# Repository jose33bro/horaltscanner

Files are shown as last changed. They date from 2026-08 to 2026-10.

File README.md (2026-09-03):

# HoralScanner

**Modular 3D Scanner & Reconstruction System**  
Raspberry Pi 4 + Creality V4.2.2 with custom USB firmware






---

## 🎯 What is HoralScanner?

HoralScanner is a complete **3D scanning and reconstruction system** built from the ground up for **Raspberry Pi 4**. It uses:

✅ **Custom STM32 USB firmware** — Direct motor/stepper control via USB CDC protocol  
✅ **Flask REST API** — Lightweight web service on port 5000  
✅ **Multi-sensor fusion** — Lidar (TF-Luna) + dual lasers + cameras (USB + CSI)  
✅ **3D reconstruction** — Open3D-powered point cloud processing  
✅ **Web dashboard** — Real-time control & monitoring  
✅ **Systemd auto-start** — Service runs on boot  

Perfect for:
- 🔬 Academic 3D scanning research
- 🖨️ Retrofitting old 3D printers
- 🎓 Educational robotics projects
- 🏭 Industrial inspection systems

---

## 🚀 Quick Start (Choose Your Path)

### Path A: Fresh Raspberry Pi OS (Recommended)
```bash
# 1. Flash latest Raspberry Pi OS to SD card
# Download: https://www.raspberrypi.com/software/

# 2. SSH into your Pi
ssh pi@raspberrypi.local

# 3. One-line installation
sudo bash -c "curl -sSL https://raw.githubusercontent.com/jose33bro/horaltscanner/main/setup_pi.sh | bash"

# 4. Reboot
sudo reboot

# 5. Access dashboard
# Open browser: http://<your-pi-ip>:5000
```
**Time:** 30-45 minutes | **Difficulty:** ⭐ Easy

---

### Path B: Manual Setup
See [QUICK_START.md](QUICK_START.md) for step-by-step instructions.

---

## 📊 Web Dashboard

Access at: `http://<your-pi-ip>:5000`

**Features:**
- 🔴 **Lasers:** Toggle left/right laser
- 🟡 **LED RGB:** Color picker + presets
- ⚙️ **Motors:** Move X/Y/Z by mm, homing, stop
- 💨 **Fans:** Control Pi/Creality/temperature fans (0-100%)
- 🌡️ **Temperature:** Real-time board sensor reading
- 📡 **Status:** GPIO & STM32 driver health

---

## 🔌 Hardware Setup

**Required:**
- Raspberry Pi 4 (4GB+)
- Creality V4.2.2 board (STM32F103RET6)
- USB cable (Micro-B, data-capable)
- Power supply

**GPIO Mapping (Raspberry Pi):**
```
GPIO27  → Laser Left (PWM-capable MOSFET, binary API)
GPIO22  → Laser Right (PWM-capable MOSFET, binary API)
GPIO18  → LED Red (PWM)
GPIO13  → LED Green (PWM)
GPIO19  → LED Blue (PWM)
GPIO23  → Pi Fan (PWM)
```

**STM32F103 Mapping (Creality V4.2.2):**
```
PC2/PB9/PC3  → Stepper X (step/dir/enable)
PB8/PB7/PC3  → Stepper Y (step/dir/enable)
PB6/PB5/PC3  → Stepper Z (step/dir/enable)
PA0          → Creality Fan (PWM)
PA8          → Temperature Fan (PWM)
PC5          → Board Temp Sensor
```

See `hardware/wiring_diagram.md` for complete pinout.

---

## 📡 REST API

All endpoints return JSON. Base URL: `http://<your-pi-ip>:5000`

### Lasers
```bash
POST /api/laser/left       {"state": true}      # Turn ON
POST /api/laser/right      {"state": false}     # Turn OFF
GET  /api/laser/status                          # Get both status
```

### LED
```bash
POST /api/led/color        {"r": 255, "g": 0, "b": 0}  # Set to red
GET  /api/led/status                            # Get current color
```

### Motors
```bash
POST /api/move/x           {"mm": 10.0}         # Move X by 10mm
POST /api/home/x                                # Home X axis
POST /api/home/all                              # Home all axes
POST /api/motor/stop       {"axis": "z"}        # Stop Z motor
GET  /api/motor/status                          # Get positions
```

### Fans
```bash
POST /api/fan/pi           {"percent": 50}      # Set Pi fan to 50%
POST /api/fan/creality     {"speed": 0.75}      # Set Creality fan
POST /api/fan/temperature  {"pwm": 0.5}         # Set temp fan
GET  /api/fan/status                            # Get all speeds
```

### Temperature
```bash
GET  /api/temperature/board                     # Get °C
GET  /api/temperature/all                       # Get all sensors
```

### System
```bash
GET  /api/status                                # Health check
GET  /                                          # Web dashboard
```

**Full API Reference:** See [USAGE.md](USAGE.md)

---

## 📁 Project Structure

```
horaltscanner/
├── software/
│   ├── api/                    # Flask API server
│   │   ├── horalscanner_api.py # Main entry point (port 5000)
│   │   ├── motor_control.py    # X/Y/Z axis orchestration
│   │   ├── laser_control.py    # GPIO laser control
│   │   ├── led_control.py      # RGB LED control
│   │   ├── camera_driver.py    # USB & Pi Camera capture
│   │   ├── lidar_driver.py     # TF-Luna lidar driver
│   │   └── scanner_engine.py   # Multi-sensor scan orchestration
│   │
│   ├── web/                    # Web dashboard (HTML/CSS/JS)
│   │   ├── index.html
│   │   ├── app.js
│   │   └── style.css
│   │
│   ├── drivers/                # Hardware abstraction
│   │   ├── stm32_driver.py     # Creality USB interface
│   │   └── gpio_driver.py      # Raspberry Pi GPIO
│   │
│   ├── scripts/                # Utilities
│   │   └── update.sh           # Auto-update script
│   │
│   └── tests/                  # Test suite
│       └── test_*.py
│
├── firmware/
│   ├── creality_v422/
│   │   └── usb_firmware.c      # STM32F103 firmware (custom USB protocol)
│   │
│   └── raspberry_pi/
│       ├── usb_driver.py       # Python USB CDC driver
│       ├── motor_control.py    # Motor orchestration
│       ├── camera_acquisition.py
│       ├── lidar_acquisition.py
│       └── scanner_app.py      # Main scanning app
│
├── hardware/
│   ├── wiring_diagram.md       # GPIO & pin mappings
│   └── README.md
│
├── docs/
│   └── usb_protocol.md         # USB CDC protocol spec
│
├── setup_pi.sh                 # Complete Pi setup script
├── QUICK_START.md              # Installation guide (3 paths)
├── DEPLOYMENT.md               # Production deployment guide
├── USAGE.md                    # API reference & examples
├── CHANGELOG.md                # Version history
├── requirements.txt            # Python dependencies
└── VERSION                     # Version number
```

---

## 🛠️ Technology Stack

| Layer | Technology | Purpose |
|---|---|---|
| **Language** | Python 3.9+ (69%) | Backend, drivers, scanning logic |
| **Web Framework** | Flask 2.3+ | REST API server |
| **Hardware I/O** | RPi.GPIO, gpiozero | GPIO control |
| **USB/Serial** | pyserial | STM32 communication |
| **Vision** | OpenCV 4.5+ | Camera capture, image processing |
| **3D** | Open3D 0.12+ | Point cloud reconstruction |
| **Math** | NumPy, SciPy | Scientific computing |
| **Frontend** | Vanilla JS, HTML5, CSS3 | Web dashboard |
| **Init** | systemd | Service management |
| **OS** | Raspberry Pi OS (Bookworm) | Base system |

---

## 📋 Scripts Included

### `setup_pi.sh` — Full Setup
```bash
sudo bash setup_pi.sh --full          # Fresh system + code + service
sudo bash setup_pi.sh --install       # Skip system updates
sudo bash setup_pi.sh --update        # Update code only
sudo bash setup_pi.sh --quick-test    # Test imports
```

### `software/scripts/update.sh` — Auto-Update
```bash
bash /home/pi/horaltscanner/software/scripts/update.sh
```
- Backs up current state
- Pulls latest code
- Updates Python deps
- Restarts service

---

## ✅ Verification Checklist

After installation, verify:

- [ ] SSH access to Pi works
- [ ] Service running: `sudo systemctl status horalscanner`
- [ ] Web dashboard loads: `http://<pi-ip>:5000`
- [ ] GPIO driver connected (in dashboard Status card)
- [ ] STM32 driver connected (when board is powered)
- [ ] Can toggle laser via dashboard or API
- [ ] Can read board temperature
- [ ] Can move motors (after homing)

---

## 🐛 Troubleshooting

### Service won't start
```bash
# Check logs
sudo journalctl -u horalscanner -n 50

# If GPIO fails
sudo usermod -a -G gpio pi
sudo reboot
```

### Can't connect to Creality board
```bash
# List serial devices
ls /dev/tty*

# Check USB
lsusb
dmesg | grep -i stm32
```

### Port 5000 in use
```bash
sudo lsof -i :5000
sudo kill -9 <PID>
```

Full troubleshooting: See [DEPLOYMENT.md](DEPLOYMENT.md) or [QUICK_START.md](QUICK_START.md)

---

## 📚 Documentation

| Document | Purpose |
|---|---|
| [QUICK_START.md](QUICK_START.md) | 3 installation paths, setup verification |
| [DEPLOYMENT.md](DEPLOYMENT.md) | Production deployment, systemd, troubleshooting |
| [USAGE.md](USAGE.md) | Full API reference with cURL examples |
| [CHANGELOG.md](CHANGELOG.md) | Version history and release notes |
| `hardware/wiring_diagram.md` | Complete GPIO & pin mappings |
| `docs/usb_protocol.md` | USB CDC protocol specification |

---

## 🔐 Security Notes

⚠️ **This project is for local development/research:**

- Default user: `pi` / password: `raspberry` (change immediately!)
- API has no authentication (designed for LAN only)
- No HTTPS (use only on trusted networks)
- GPIO access available to `pi` user

For production deployment:
1. Change default password
2. Disable SSH password auth (use keys only)
3. Use firewall (ufw)
4. Add reverse proxy with authentication
5. Use VPN for remote access

---

## 📈 Performance

Typical performance on Raspberry Pi 4 (4GB):

| Task | Performance |
|---|---|
| API response time | <50ms |
| Motor command | 10-50ms |
| GPIO toggle | 1-5ms |
| Camera capture | 30-60fps (640x480) |
| Lidar scan | 5Hz (200pt/s) |
| 3D reconstruction | 1-5 min for 1000+ points |

---

## 📄 License

MIT License - See LICENSE file for details

---

## 🤝 Contributing

1. Fork the repository
2. Create a feature branch (`git checkout -b feature/amazing-feature`)
3. Commit changes (`git commit -m 'Add amazing feature'`)
4. Push to branch (`git push origin feature/amazing-feature`)
5. Open a Pull Request

---

## 📞 Support

- **Issues:** https://github.com/jose33bro/horaltscanner/issues
- **Discussions:** https://github.com/jose33bro/horaltscanner/discussions

---

## 🎉 Status

- ✅ **v1.0.0** — Stable release
  - Web dashboard
  - Flask API
  - GPIO/STM32 drivers
  - Systemd service
  - Full documentation

---

**Made with ❤️ for 3D scanning enthusiasts**

Get started now: [QUICK_START.md](QUICK_START.md)

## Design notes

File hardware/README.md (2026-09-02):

# Matériel cible

- Raspberry Pi 4 (4Go)
- Carte mère Creality V4.2.2 (STM32F103)
- Axe X: plateau tournant
- Axe Y: translation avec endstop (point 0 lidar TF-Luna)
- Axe Z: ajustement hauteur
- Lidar TF-Luna (USB)
- Caméra USB Logitech
- Caméra Pi V3 noire (CSI)
- 2 lasers pilotés via GPIO du Raspberry Pi

La logique moteur est embarquée côté firmware STM32, la synchronisation capteurs est orchestrée côté Raspberry Pi.

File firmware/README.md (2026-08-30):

# Firmware USB personnalisé (Creality V4.2.2)

Ce dossier contient une base de firmware USB custom pour STM32F103 (carte Creality V4.2.2).

## Responsabilités
- Communication USB bidirectionnelle avec le Raspberry Pi
- Commandes moteurs sur axes X/Y/Z
- Lecture endstop Y
- Point de synchronisation avec les capteurs côté Raspberry Pi

## Protocole texte minimal (USB CDC)
- `PING` → `OK PONG`
- `MOVE <AXIS> <STEPS> <SPEED>` → `OK MOVE`
- `HOME Y` → `OK HOME`
- `ENDSTOP Y` → `OK ENDSTOP <0|1>`
- `SYNC <TOKEN>` → `OK SYNC <TOKEN>`

Le code source de référence est dans `creality_v422/src/main.c`.

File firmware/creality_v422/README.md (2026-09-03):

# Firmware HoralScanner pour Creality V4.2.2

Ce firmware cible uniquement une carte Creality V4.2.2 équipée d'un
**STM32F103RET6**. Il implémente le protocole décrit dans
`docs/usb_protocol.md` sur le CH340 de la carte à 115200 bauds.

## Sécurité

- Les sorties chauffantes PA1 et PA2 sont forcées à l'arrêt.
- Les moteurs sont désactivés au démarrage, après chaque mouvement et après
  cinq secondes sans commande.
- Un déplacement vers la butée s'arrête dès que l'entrée correspondante devient
  active. Les contacts normalement fermés de X, Y et Z sont actifs à l'état
  haut lorsqu'ils s'ouvrent sur la butée.
- Une recherche d'origine est abandonnée après 120 secondes.
- Le repère Y arrête uniquement le référencement. Si PA6 est déjà actif au
  début de `HOME Y` (ou lorsque `HOME ALL` atteint Y), le plateau continue dans
  le sens de référencement jusqu'à la libération stable du repère, puis jusqu'à
  son prochain déclenchement stable. La libération et le déclenchement sont
  validés pendant 20 ms pour rejeter les rebonds. Les rotations `MOVE Y`
  franchissent toujours le repère afin que le plateau accomplisse un tour
  complet.
- Les mouvements utilisent une rampe d'accélération et de décélération pour
  éviter les résonances et pertes de pas du plateau.
- La vitesse de référencement est limitée séparément pour chaque mécanique:
  X et Z à 400 pas/s, Y à 100 pas/s après accélération progressive.
- Les trois axes partagent la sortie d'activation PC3.

Ne flashez pas ce binaire sur une carte GD32 ou une autre révision. Débranchez
les moteurs avant le premier test de communication. Vérifiez ensuite chaque
fin de course avec `ENDSTOP X`, `ENDSTOP Y` et `ENDSTOP Z` avant d'utiliser
`HOME`.

## Compilation

Depuis la racine du dépôt:

```bash
bash software/scripts/build_creality_firmware.sh
```

Le binaire est créé dans:

```text
firmware/creality_v422/build/firmware.bin
```

Le linker place l'application à `0x08007000`, après le bootloader Creality de
28 Kio. La table des vecteurs est déplacée au même endroit.

## Flash par carte microSD

1. Utilisez une carte microSD FAT32 de 8 Go ou moins.
2. Copiez uniquement le binaire à la racine, sous le nom `firmware.bin`.
3. Coupez complètement l'alimentation 24 V et débranchez l'USB.
4. Insérez la microSD, puis remettez l'alimentation 24 V.
5. Attendez 30 secondes sans couper l'alimentation.
6. Coupez l'alimentation, retirez la carte, puis reconnectez l'USB.

Le fichier est généralement renommé `FIRMWARE.CUR` après un flash réussi.
Après reconnexion au Raspberry Pi:

```bash
sudo systemctl stop horalscanner
sudo /home/pi/horaltscanner_env/bin/python3 -c \
  "import serial,time; s=serial.Serial('/dev/ttyUSB0',115200,timeout=2); time.sleep(2); s.write(b'PING\n'); s.flush(); print(repr(s.readline())); s.close()"
sudo systemctl restart horalscanner
```

La réponse attendue est `b'OK PONG\r\n'`.

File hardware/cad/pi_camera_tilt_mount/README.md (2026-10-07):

# Support orientable pour Pi Camera V3

Ce répertoire contient la base du support orientable de Pi Camera V3 et son
test d'encombrement. La plaque verticale et la tablette inférieure forment un
support en L; les deux oreilles supérieures reçoivent l'axe M3 de la caméra.

## Fichiers générés

- `stl/pi_camera_tilt_base.stl` : base orientable définitive;
- `stl/fit_test_rear_cavity_30.45x38.2.stl` : test d'encombrement à imprimer
  avant la base;
- `stl/adjustment_rod_M5x50_ball6.5_square_m3.stl` : tige d'ajustement M5
  sur 50 mm, bille Ø 6,5 mm côté caméra et carré côté roue/plateau, avec trou
  M3 central dans le carré;
- `stl/wheel_crank_50mm_square_m3.stl` : roue/crank de 50 mm de diamètre avec
  carré de montage et trou M3 central pour serrage sur plaque de 3 mm;
- `stl/camera_carrier_v3_25x24_tab4.8.stl` : berceau qui porte la carte Pi
  Camera Module 3 (noir/NoIR, 25 × 24 mm, 4 trous Ø2,5 mm en carré 21 mm) et
  se clipse entre les oreilles de la base sur l'axe M3 (tenon Ø 3,40 mm), avec
  un patin plat au dos où vient appuyer la bille de la tige d'ajustement;
- `stl/camera_front_cover_v3_clip.stl` : cache avant (côté objectif) qui
  tient la caméra sur le berceau sans vis — 4 pions se clipsent par
  pression dans les mêmes 4 trous Ø2,5 mm, en traversant la carte et le
  berceau, avec une ouverture centrale Ø11 mm pour l'objectif.

Les autres fichiers STL éventuellement présents dans ce répertoire ne sont pas
générés par `generate.py`.

## Cotes fonctionnelles de la base

- plaque verticale : 30,45 × 38,20 × 3,20 mm;
- tablette inférieure vers l'avant : projection 24,00 mm;
- parois latérales de tablette : 3,20 mm d'épaisseur et 6,20 mm de hauteur;
- rails sous la tablette : 5,00 mm de large, 16,00 mm de long et 5,00 mm de
  descente, avec un avant-trou horizontal Ø 2,70 mm dans chaque rail et une
  découpe de 3,00 mm depuis l'avant pour dégager le passage M3;
- passage de nappe du câble CSI dans la partie tablette : ouverture centrale
  vers l'avant, dans la tablette de 24,00 mm.
- oreilles : projection 8,70 mm, largeur 8,50 mm, hauteur 5,99 mm et espace
  central 5,33 mm;
- trou d'axe traversant : Ø 3,40 mm;
- trou de fixation M5 sur la plaque verticale, centré entre les oreilles et à 22,00 mm du haut;
- fenêtre CSI dans la plaque verticale : 18,00 × 9,56 mm, centrée en bas et décalée vers l'avant;
- encoches de dégagement dans les parois latérales de la tablette (côté
  intérieur) là où la carte caméra (25,00 mm de large) est plus large que
  l'écart utile entre parois (24,05 mm);
- poche de dégagement dans la face supérieure de la tablette, sous la zone
  balayée par le bord bas du berceau pendant le pivotement (voir plage de
  réglage ci-dessous) : sans elle, le berceau coince contre la tablette dès
  une fraction de degré dans un des deux sens de rotation.

## Plage de réglage de l'inclinaison

Le berceau pivote autour de l'axe M3 des oreilles; au repos (0°) il touche
la tablette, qui sert de butée naturelle d'un côté. La plage utile réelle,
vérifiée géométriquement (volumes de recouvrement nuls entre solides), est
**-15° à +9°** par rapport au repos :

- jusqu'à -15° : dégagement complet, aucun contact parasite;
- au-delà de +9° : le berceau commence à empiéter dans la fenêtre CSI de la
  plaque verticale (pas un contact matière, mais un risque de pincer la
  nappe du câble CSI qui passe par cette fenêtre).

Cette plage asymétrique convient à l'usage prévu : la caméra est déjà
orientée vers le bas (vers le plateau tournant) au repos, donc le sens
disponible le plus large (-15°, qui l'incline encore plus vers le bas) est
celui qui compte le plus.

## Cotes du berceau caméra (`camera_carrier_v3_25x24_tab4.8.stl`)

- plaque porte-caméra : 25,00 × ~29,00 × 2,00 mm (hauteur ajustée pour
  rejoindre le bas des oreilles), espacée de 9,00 mm derrière la face avant
  de la plaque principale (jeu pour la tige d'ajustement et pour que le
  bord bas du berceau dégage la plaque sur toute la plage de réglage);
- 4 trous de fixation M2/M2,5 Ø 2,50 mm en carré de 21,00 mm, cotes
  officielles du Camera Module 3 (25 × 24 mm, standard ou NoIR);
- tenon de charnière : largeur 4,80 mm (jeu dans l'espace de 5,33 mm entre
  les oreilles), même profil arrondi que les oreilles, trou d'axe Ø 3,40 mm
  aligné avec celui de la base; profondeur dimensionnée pour ne chevaucher
  que la propre plaque du berceau (fusion solide), sans jamais pénétrer
  dans la plaque principale;
- patin plat au dos (remplace l'ancienne fossette sphérique) : rayon
  6,00 mm, profondeur 0,60 mm, où vient appuyer la bille de la tige. Une
  sphère contre un plan garde un contact valide à n'importe quel angle,
  contrairement à une fossette sphérique de même rayon que la bille, dont
  la plage utile ne dépassait que ±2,4° avant perte de contact.

## Cotes du cache avant (`camera_front_cover_v3_clip.stl`)

- plaque : 25,00 × 24,00 × 1,60 mm, plaquée contre la face avant de la carte
  caméra (côté objectif);
- ouverture centrale Ø 11,00 mm, centrée sur le carré de trous de montage,
  pour dégager l'objectif;
- 4 pions de clipsage Ø 2,30 mm (léger serrage dans les trous Ø 2,50 mm de
  la carte), longueur de pénétration ~2,90 mm (épaisseur carte + berceau,
  sans atteindre la face arrière du berceau), pointe conique de 0,80 mm pour
  faciliter l'insertion. Remplace les vis/écrous M2,5 : pousser le cache en
  face, les pions traversent la carte et se bloquent par friction dans les
  trous du berceau.

## Génération

Le générateur paramétrique `generate.py` dépend des bindings OpenCascade
fournis par le paquet `cadquery-ocp`. Dans un environnement Python dédié :

```bash
python3 -m pip install cadquery-ocp
python3 hardware/cad/pi_camera_tilt_mount/generate.py
```

Exécuter la commande depuis la racine du dépôt. Elle vérifie les solides avant
l'export et remplace les six STL listés ci-dessus.

## Impression et montage

1. Imprimer d'abord le test d'encombrement à plat et vérifier l'espace arrière.
2. Imprimer la base avec le grand dos de la plaque contre le plateau.
3. Utiliser des supports « Everywhere », angle de surplomb 55°, densité 12 %,
   interface activée (2 couches) et distance Z de 0,22 mm.
4. Poser la carte Pi Camera Module 3 contre la face avant du berceau
   (`camera_carrier_v3_25x24_tab4.8.stl`), trous alignés.
5. Clipser le cache avant (`camera_front_cover_v3_clip.stl`) par-dessus : les
   4 pions traversent les trous de la carte et se bloquent par pression dans
   les trous du berceau — pas de vis ni d'écrou nécessaires.
6. Installer le berceau (carte + cache) entre les oreilles de la base avec
   l'axe M3 (pivot), sans le bloquer serré pour qu'il puisse encore pivoter.
7. Visser la tige d'ajustement (`adjustment_rod_M5x50_ball6.5_square_m3.stl`)
   dans le bossage taraudé M5 au dos de la plaque, bille côté caméra, jusqu'à
   ce qu'elle appuie contre le patin plat au dos du berceau.
8. Clipser la roue (`wheel_crank_50mm_square_m3.stl`) sur le carré de la tige
   avec une vis M3 et tourner pour régler finement l'inclinaison (plage
   utile -15°/+9°, voir « Plage de réglage de l'inclinaison » plus haut); le
   berceau pivote autour de l'axe des oreilles.
9. Fixer la base par les deux rails inférieurs avec des vis M3.

Le profil d'impression détaillé est documenté dans
[`../../../materiel/README_support_camera_pi_pivot_reglable.md`](../../../materiel/README_support_camera_pi_pivot_reglable.md).

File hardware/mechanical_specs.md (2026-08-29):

# HoralScanner — Mechanical Specifications

## Design Reference Frame

```
        Z-Axis (Height)
             ↑
             |
   Y-Axis ←--+--→ X-Axis (Rotation)
       (Forward/Back)
             
    Rear (Y=0) -------- Front (Y=100)
       ↑                    ↑
    Endstop         Object detection
```

---

## Ball Screw Specifications

### M5 × 40 Assembly (All Axes)

| Parameter | Value | Notes |
|---|---|---|
| **Thread Pitch** | M5 × 0.8 mm | ISO metric |
| **Ball Diameter** | Ø6.5 mm | Grade 25 hardened steel |
| **Ball Preload** | Light (1–2 N/mm²) | Reduces backlash to <0.1 mm |
| **Lead** | 5 mm/rev | 1 revolution = 5 mm travel |
| **Maximum Speed** | 20,000 steps/sec | Stepper limit (from motor_control.py) |
| **Max Linear Speed** | ~100 mm/sec | Calculated: 20k steps/sec ÷ 3200 steps/mm × 16 microsteps |
| **Preload Spring** | Light spring or adjustable collar | Rear bearing (fixed); front bearing (floating) |
| **Lubrication** | NLGI-2 lithium grease | Reapply every 500 hours of operation |

### Calculation: Steps per mm
```
Steps/mm = (200 steps/rev × 16 microsteps) / 5 mm pitch
         = 3200 / 5
         = 640 steps/mm
```

### Motion Limits

| Axis | Travel Range | Position Min | Position Max | Purpose |
|---|---|---|---|---|
| **X (Rotation)** | 0–360° | 0 mm | 360 mm | Continuous rotation platform |
| **Y (Forward/Back)** | 0–100 mm | 0 mm (rear, endstop) | 100 mm (front) | Linear scan axis |
| **Z (Height)** | 0–50 mm | 0 mm (+5 mm offset) | 50 mm | Camera height adjustment |

---

## 3D-Printed Parts (PLA)

### Camera Support Plate

**Overall Dimensions:**
```
   Front
      ↑
    7 mm (width)
      ↑
   ┌──────────────┐
   │  Socket      │ 1 mm (height/thickness)
   │   Ø6.9 mm    │ ← centered
   │  (centered)  │
   │    │││       │ ← 4 petal retainers (depth)
   └──┴─┴─┴──────┘
   28.05 mm (length)
```

**Key Specifications:**

| Feature | Dimension | Tolerance | Notes |
|---|---|---|---|
| **Length** | 28.05 mm | ±0.1 mm | Attachment footprint |
| **Width** | 7 mm | ±0.2 mm | Camera connector clearance |
| **Thickness** | 1 mm | ±0.2 mm | Minimal weight |
| **Socket Diameter** | Ø6.9 mm | ±0.05 mm | Logitech USB camera lens fit |
| **Socket Depth** | 4 mm | ±0.1 mm | Retainer petal depth |
| **Petal Retainers** | 4× radial petals | — | Grip camera housing without glue |
| **M3 Clearance Holes** | Ø3.2 mm | ±0.1 mm | Screw pass-through (not tapped) |
| **Hole Spacing** | 2× on 14 mm centers | ±0.2 mm | Frame attachment points |
| **Socket Centering** | Center ±0.1 mm | — | Optical axis alignment |

**Material Properties:**
- **Infill:** 15% grid pattern (sufficient for non-load-bearing bracket)
- **Layer Height:** 0.15 mm (for surface finish)
- **Support Material:** Breakaway supports on underside; clean before installation
- **Print Speed:** 60–80 mm/s (avoid warping at thin cross-section)
- **Bed Temp:** 60°C; Nozzle: 210°C

**Load Limits:**
- **Supported Mass:** <200 g (USB camera + lens)
- **Retention Force:** ~5 N (petal friction)
- **Failure Mode:** Petal cracking under excessive insertion torque

---

### Base Plate

**Overall Dimensions:**
```
    M5 Hole
      ↓ (Rear side)
    ┌────────────────────────┐
    │                        │
    │      BASE PLATE        │  Vertical offset: +5 mm
    │      (PLA)             │  from origin (Y=0, Z=0 ref)
    │                        │
    └─────────────────────────┘
      Rear (Y=0) ←→ Front (Y=100)
```

**Key Specifications:**

| Feature | Specification | Tolerance | Notes |
|---|---|---|---|
| **Length** | 100 mm | ±1 mm | Full Y-axis travel |
| **Width** | 50 mm | ±1 mm | Z-axis carriage mount |
| **Thickness** | 3 mm | ±0.2 mm | Structural rigidity |
| **M5 Tapped Hole** | M5 × 0.8 ISO | ±0.1 mm | Ball screw mounting (Z-axis) |
| **Hole Position** | Center rear, 10 mm from edge | ±0.5 mm | — |
| **Hole Type** | Tapped (M5×0.8) or threaded insert | — | Must support axial load of ball screw |
| **Vertical Offset Reference** | +5 mm above absolute origin | ±0.5 mm | **Calibration height** for TF-Luna Y-sync |
| **Orientation Marking** | "Rear → Front" engraved or labeled | — | Assembly guide |
| **Surface Finish** | Smooth (post-processed if needed) | — | Reduce friction on Y-carriage |

**Material Properties:**
- **Infill:** 25% (load-bearing structural part)
- **Layer Height:** 0.2 mm (strength > finish)
- **Support Material:** None (print with flat base down)
- **Print Speed:** 50–60 mm/s (ensure dimensional accuracy)
- **Bed Temp:** 60°C; Nozzle: 210°C

**Load Limits:**
- **Supported Mass:** <500 g (full scanner head + camera + laser)
- **M5 Thread Tensile Strength:** ~2 kN (PLA nominal)
- **Deflection:** <0.5 mm under full load (measure with dial indicator)

**Mounting to Frame:**
- Secure to Z-carriage with M3 fasteners (2× clearance holes if present)
- Use M3 nylon washers under screw heads to reduce PLA stress concentration
- Apply loctite (medium strength) to M5 ball screw socket

---

## Critical Dimensions & Calibration

### Camera Support Plate → Z-Carriage Interface

**Assembly Sequence:**

1. **Mount plate on Z-carriage:**
   - Position: Centered on carriage, front face (toward object)
   - Height: Flush with carriage top surface
   - Fasteners: M3×10 pan-head screws, 1.5–2 N·m torque

2. **Insert camera into socket:**
   - Logitech USB camera lens first (Ø6.9 mm)
   - Push gently until 4 petals engage connector housing
   - Verify horizontal (spirit level)
   - Do NOT force (risk breaking petals)

3. **Cable routing:**
   - USB cable exits toward rear
   - 100 mm slack for Y-motion
   - Cable tie at rear frame

**Clearance Check:**
- **Plate to ball screw:** 1 mm minimum (avoid binding during Z travel)
- **Socket to camera:** 0 mm (tight fit is intentional; creates retention)
- **Camera lens to object:** 50–200 mm working distance

---

### Base Plate → Frame Interface

**M5 Tapped Hole (Ball Screw Mounting):**

1. **Prepare hole:**
   - Clean PLA threads of any residual plastic
   - Test-thread M5 machine screw (should turn smoothly, no crunching)
   - If threads damaged, drill out Ø5.5 mm and install **M5 threaded insert** (helicoil type)

2. **Install ball screw:**
   - Thread M5×40 ball screw into tapped hole
   - Screw in until **slight resistance** (ball nut engagement)
   - Rotate screw manually: should turn **freely with light resistance**
   - If stuck: back out and apply light grease to threads

3. **Secure with lock nut:**
   - Thread M5 lock nut onto exposed ball screw
   - Torque: 10–15 N·m (prevents axial motion but allows rotation)
   - Verify screw doesn't rotate when nut is tightened

**Vertical Offset Calibration (+5 mm):**
- Measure Z-position of base plate **relative to its lowest position**
- When Z-axis is fully retracted, base plate should be **5 mm above origin**
- This ensures TF-Luna (mounted on Y-carriage) can measure object at optimal distance (50–100 mm)
- **Do NOT change this offset** without recalibrating `lidar_driver.py` offset constant

---

## Endstop Configuration

### Y-Axis Endstop (Rear Limit, Y=0)

**Mechanical:**
- **Type:** Microswitch, normally-open (NO), lever-activated
- **Mounting:** Fixed to rear frame or carriage rail
- **Activation Point:** Y-carriage contacts lever exactly at Y=0
- **Travel Distance to Stop:** <2 mm (minimal over-travel)

**Electrical:**
- **Wiring:** Common pin → GND; NO pin → Creality endstop input
- **Pull-up:** Enabled in Creality firmware (internal 10k resistor)
- **Logic:** Active LOW (switch closes = GND signal)

**Calibration:**
1. Jog Y-axis toward rear manually using dashboard
2. When carriage contacts endstop, listen for **click** from microswitch
3. In `motor_control.py`, set `home_offset_y = 0`
4. Run `api/home/y` endpoint; verify position resets to 0.0

---

## Electrical Connector Specifications

### Stepper Motor Connectors

**Wiring (4-wire, bipolar NEMA 17):**
```
Pin 1: Coil A+  (Red)
Pin 2: Coil A-  (Green)
Pin 3: Coil B+  (Blue)
Pin 4: Coil B-  (Black)

Creality V4.2.2 Motor Header Layout:
┌──────────┐
│ 1  2  3  4 │  (Typical: GND, STEP, DIR, +V)
│ GND STP DIR +V│
└──────────┘
```

**Cable Specifications:**
- **Type:** 4-conductor shielded cable (UTP acceptable for short runs)
- **AWG:** 22–26 gauge (1 m runs acceptable)
- **Connector:** Dupont 2.54mm female headers or equivalent
- **Length:** <1 m (minimize noise coupling)

---

## Tolerance & Fit Summary

| Component | Critical Tolerance | Rationale |
|---|---|---|
| **Camera Socket (Ø6.9)** | ±0.05 mm | Optical axis alignment (±0.1 mm lateral error acceptable) |
| **Ball Screw Hole (M5)** | ±0.1 mm | Thread engagement; prevent loosening |
| **M3 Fastener Holes** | ±0.2 mm | Clearance holes (not critical) |
| **Petal Depth (4 mm)** | ±0.1 mm | Retention force (too shallow = camera falls out) |
| **Vertical Offset (+5 mm)** | ±0.5 mm | LiDAR range calibration (software compensates) |
| **Base Plate Length (100 mm)** | ±1 mm | Non-critical (travel programmatically limited) |

---

## Testing & Verification Checklist

- [ ] Ball screws rotate freely by hand (all three axes)
- [ ] Camera plate is level (spirit level check)
- [ ] Socket Ø6.9 grips camera without excessive force
- [ ] M5 tapped hole threads cleanly (test with machine screw)
- [ ] Endstop activates at exactly Y=0 (measure with caliper)
- [ ] Motor homing completes successfully (check dashboard)
- [ ] LiDAR reads stable distances at various heights (100–300 mm range)
- [ ] Camera focus is sharp at intended working distance
- [ ] No binding or grinding sounds during axis motion
- [ ] USB camera frame rate stable (30 fps minimum)

---

## Version History

| Date | Version | Changes |
|---|---|---|
| 2026-08-29 | 1.0.0 | Initial mechanical specs: ball screws, PLA parts, tolerances, calibration procedure |

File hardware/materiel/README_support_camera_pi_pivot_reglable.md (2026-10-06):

# Support caméra Pi v3 noir – pivot réglable

Ce document décrit l’impression et l’assemblage de la base orientable de Pi
Camera V3 (Klipper + PLA Creality Hyper Series). Les cotes et la génération du
modèle sont documentées dans
[`../cad/pi_camera_tilt_mount/README.md`](../cad/pi_camera_tilt_mount/README.md).

## Fichiers STL

- `hardware/cad/pi_camera_tilt_mount/stl/pi_camera_tilt_base.stl`
- `hardware/cad/pi_camera_tilt_mount/stl/fit_test_rear_cavity_30.45x38.2.stl`
- `hardware/cad/pi_camera_tilt_mount/stl/adjustment_rod_M5x50_ball6.5_square_m3.stl`
- `hardware/cad/pi_camera_tilt_mount/stl/wheel_crank_50mm_square_m3.stl`
- `hardware/cad/pi_camera_tilt_mount/stl/camera_carrier_v3_25x24_tab4.8.stl`
- `hardware/cad/pi_camera_tilt_mount/stl/camera_front_cover_v3_clip.stl`

## Fonction mécanique

### Base pivot caméra
- Pièce : `pi_camera_tilt_base.stl`
- Fenêtre CSI : **18,00 × 9,56 mm** dans la plaque verticale, centrée bas et décalée vers l'avant.
- Deux oreilles reçoivent la caméra et son axe traversant M3.
- Les deux rails inférieurs reçoivent une vis M3 depuis chaque côté, avec un
  dépouille de 3,00 mm depuis l'avant pour dégager le passage M3.
- La plaque verticale porte un trou M5 centré entre les oreilles, à 22,00 mm du
  haut pour la fixation mécanique.
- La partie tablette de 24,00 mm reçoit un passage central pour la nappe
  CSI, orienté vers l'avant depuis le centre.

### Berceau caméra
- Pièce : `camera_carrier_v3_25x24_tab4.8.stl`
- Porte la carte Pi Camera Module 3 (noir/NoIR), 25 × 24 mm, 4 trous Ø 2,50 mm
  en carré de 21,00 mm (cotes officielles Raspberry Pi).
- Tenon de charnière (4,80 mm de large) qui se clipse dans l'espace de
  5,33 mm entre les oreilles de la base, aligné sur le même axe M3 Ø 3,40 mm.
- Fossette au dos (Ø bille + 0,30 mm de jeu, 1,00 mm de profondeur) alignée
  sur le bossage de réglage de la base : la bille de la tige d'ajustement
  s'y loge pour ne pas glisser pendant le réglage.

### Cache avant (clip, sans vis)
- Pièce : `camera_front_cover_v3_clip.stl`
- Plaque 25 × 24 × 1,60 mm avec ouverture Ø 11,00 mm pour l'objectif.
- 4 pions Ø 2,30 mm (serrage léger dans les trous Ø 2,50 mm de la carte),
  pointe conique pour l'insertion, longueur de pénétration ~2,90 mm
  (traverse la carte + une grande partie du berceau par friction).
- Remplace les vis/écrous M2,5 : on clipse la carte entre le berceau et ce
  cache, sans outil.

## Assemblage

1. Imprimer d'abord `fit_test_rear_cavity_30.45x38.2.stl` et valider
   l'encombrement.
2. Poser la carte Pi Camera Module 3 contre la face avant du berceau
   (`camera_carrier_v3_25x24_tab4.8.stl`), trous alignés.
3. Clipser le cache avant (`camera_front_cover_v3_clip.stl`) par-dessus : les
   4 pions traversent les trous de la carte et se bloquent par pression dans
   les trous du berceau — pas de vis ni d'écrou nécessaires.
4. Installer le berceau (carte + cache) entre les oreilles de la base avec
   l'axe M3 traversant comme pivot, sans serrer à fond.
5. Visser la tige d'ajustement dans le bossage M5 au dos de la plaque jusqu'à
   ce qu'elle se loge dans la fossette au dos du berceau, puis clipser la roue
   sur le carré avec une vis M3.
6. Tourner la roue pour régler finement l'inclinaison.
7. Fixer la base horizontalement au support par les deux rails inférieurs avec
   une vis M3 de chaque côté.

## Réglages impression recommandés (Klipper + Creality Hyper PLA, buse 0.4)

- Temp buse : **215°C**
- Temp bed : **60°C**
- Hauteur couche : **0.16 mm**
- 1ère couche : **0.20 mm**
- Largeur ligne : **0.42 mm**
- Parois : **6**
- Top/Bottom : **7 / 7**
- Infill : **35%** (Gyroid/Cubic)
- Ventilation : **100% dès couche 3**
- Vitesse paroi externe : **22 mm/s**
- Vitesse paroi interne : **35 mm/s**
- Vitesse infill : **50 mm/s**
- Vitesse travel : **160 mm/s**
- Brim : **6 mm base**, **8 mm tige**, **3–5 mm roue**
- Compensation XY : **-0.04 mm** (point de départ)

Profil complet (start/end G-code Klipper, réglages support détaillés) :
[`PRINT_PROFILE_klipper_creality_hyper_pla.txt`](./PRINT_PROFILE_klipper_creality_hyper_pla.txt).

## Orientation / supports

### `pi_camera_tilt_base.stl`
- Orientation : grand dos de la plaque contre le plateau.
- Supports : **Oui**
  - Type : Everywhere
  - Overhang : 55°
  - Densité : 12%
  - Interface : ON (2 couches)
  - Z distance : 0.22 mm

### `camera_carrier_v3_25x24_tab4.8.stl`
- Orientation : dos de la plaque (côté fossette) contre le plateau.
- Supports : généralement pas nécessaires (pièce plate, tenon fin en
  surplomb léger) — activer « Everywhere » si le tenon accroche mal.

### `camera_front_cover_v3_clip.stl`
- Orientation : face des pions contre le plateau (pions imprimés en
  surplomb léger vers le haut, cône vers le haut).
- Supports : pas nécessaires si orienté ainsi; sinon activer « Everywhere »
  pour les pions.

## Génération STL

Depuis la racine du repo :

```bash
python3 -m pip install cadquery-ocp
python3 hardware/cad/pi_camera_tilt_mount/generate.py
```

## Notes
- La commande régénère les six STL listés ci-dessus : la base, le test
  d'encombrement, la tige d'ajustement, la roue/crank, le berceau caméra et
  le cache avant à clips.

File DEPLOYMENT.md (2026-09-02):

# HoralScanner — Deployment Guide

## System Requirements

| Component | Requirement |
|---|---|
| OS | Raspberry Pi OS (Bullseye/Bookworm) or any Debian-based Linux |
| Python | 3.9 + |
| Hardware | Raspberry Pi 4 (recommended) + Creality V4.2.2 board via USB |
| Network | Local LAN access on port 5000 |

## Installation

### 1. Clone the repository

```bash
git clone https://github.com/jose33bro/horaltscanner.git
cd horaltscanner
```

### 2. Create a virtual environment

```bash
python3 -m venv ~/horaltscanner_env
source ~/horaltscanner_env/bin/activate
```

### 3. Install dependencies

```bash
pip install flask gpiozero pyserial
```

### 4. Verify hardware connections

- Raspberry Pi GPIO pins wired as per `hardware/wiring_diagram.md`
- Creality V4.2.2 board connected via USB (`/dev/ttyUSB0` or `/dev/ttyACM0`)

### 5. Test manually

```bash
cd software
python -m api.horalscanner_api
```

Open `http://<raspberry-pi-ip>:5000` in a browser — you should see the dashboard.

## systemd Service Configuration

The service file lives at `/etc/systemd/system/horalscanner.service`.

### Example service file

```ini
[Unit]
Description=HoralScanner 3D Scanner API
After=network.target

[Service]
Type=simple
User=pi
WorkingDirectory=/home/pi/horaltscanner/software
ExecStart=/home/pi/horaltscanner_env/bin/python -m api.horalscanner_api
Restart=always
RestartSec=10
StandardOutput=journal
StandardError=journal

[Install]
WantedBy=multi-user.target
```

### Enable and start

```bash
sudo systemctl daemon-reload
sudo systemctl enable horalscanner
sudo systemctl start horalscanner
sudo systemctl status horalscanner
```

### Check logs

```bash
sudo journalctl -u horalscanner -f
```

## Production Server (Gunicorn)

The Flask development server (`python -m api.horalscanner_api`) is
**single-threaded and unsuitable for production**: it handles one HTTP
request at a time, so while a client is streaming an MJPEG preview or
polling `/api/model/status`, every other request (scan control, status
checks, UI page loads) is blocked. Even though 3D reconstruction now runs
on a background thread and returns immediately, the dev server itself
cannot serve multiple *concurrent* requests, which limits the benefit of
that async work.

For production/RPi4 deployments, run the API behind
[Gunicorn](https://gunicorn.org/) with the `gevent` worker class, which
gives cooperative, non-blocking concurrency well suited to a Raspberry Pi's
limited CPU cores:

```bash
pip install -r requirements.txt  # installs gunicorn + gevent
cd software
gunicorn --workers 1 --worker-class gevent --bind 0.0.0.0:5000 "api:create_app()"
```

- `--workers 1`: hardware acquisition must have exactly one owning process.
  Multiple worker processes would each create independent GPIO, serial, camera,
  and scan-session state and are unsafe for physical scanning.
- `--worker-class gevent`: cooperative greenlets inside each worker so
  blocking I/O (camera reads, file responses) doesn't stall other
  in-flight requests on that worker.

### systemd service using Gunicorn

Update the `ExecStart` line in the service file above to use Gunicorn
instead of the Flask dev server:

```ini
ExecStart=/home/pi/horaltscanner_env/bin/gunicorn --workers 1 --worker-class gevent --bind 0.0.0.0:5000 "api:create_app()"
```

Then reload and restart as usual:

```bash
sudo systemctl daemon-reload
sudo systemctl restart horalscanner
```

## Updating

```bash
cd ~/horaltscanner
git pull origin main
sudo systemctl restart horalscanner
```

## Troubleshooting

| Symptom | Cause | Fix |
|---|---|-----|
| `Address already in use` | Another process on port 5000 | `sudo lsof -i :5000` and kill it |
| `GPIO driver unavailable` | Missing `gpiozero` or wrong user | Install gpiozero; add user to `gpio` group |

### Open3D sur Raspberry Pi OS 64 bits

PyPI ne publie pas de roue Open3D 0.19.0 pour Linux `aarch64`. Le dépôt fournit
donc un installateur qui compile les sources officielles sans interface
graphique:

```bash
cd /home/pi/horaltscanner
bash software/scripts/install_open3d_pi.sh
sudo systemctl restart horalscanner
```

La compilation utilise deux tâches par défaut pour limiter la mémoire sur le
Raspberry Pi. Cette valeur peut être ajustée avec `OPEN3D_BUILD_JOBS`.

Documentation officielle:
https://github.com/isl-org/Open3D/blob/v0.19.0/docs/arm.rst
| `STM32 driver unavailable` | USB not connected / wrong port | Check `dmesg | grep tty`; update serial port in config |
| `Failed to read board temperature` | STM32 not responding | Verify firmware is flashed and USB cable is data-capable |
| Service crashes at startup | Python import error | Check `journalctl -u horalscanner -n 50` for traceback |

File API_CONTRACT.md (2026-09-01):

# API Contract

Confirmed request/response payloads for the HoralScanner REST API
(`software/api/horalscanner_api.py`), validated on live Raspberry Pi hardware.

## Fans

`POST /api/fan/creality`
`POST /api/fan/temperature`
`POST /api/fan/pi`

Accepted payload (exactly one of the following keys):

| Key | Type  | Range | Notes |
|---|---|---|---|
| `speed` | float | `0.0`-`1.0`| Preferred, PWM duty cycle. |
| `pwm` | float | `0.0`-`1.0`| Alias for `speed`. |
| `percent` | float | `0`-`100`  | Converted internally to `speed / 100.0`.  |

Example:

```bash
curl -X POST http://127.0.0.1:5000/api/fan/creality \
  -H "Content-Type: application/json" \
  -d '{"speed": 0.5}'
```

`{"enabled": true}` and raw integers in the `0..255` range are **not**
accepted and return `400 Invalid fan speed value` (missing/out-of-range key).

`GET /api/fan/status` returns the current speed of every fan.

## Lasers

`POST /api/laser/<side>` where `<side>` is `left` or `right`.

```json
{ "state": true }
```

`GET /api/laser/status` returns `{"left": bool, "right": bool}`.

## RGB LED

`POST /api/led/color`

```json
{ "r": 0, "g": 0, "b": 255 }
```

Each channel is an integer `0..255`.

`GET /api/led/status` returns the current `{"r": 0, "g": 0, "b": 0}` values.

## USB Camera

`GET /api/camera/usb/status`

```json
{ "success": true, "camera": "usb", "available": true }
```

`available` is `true` only if the camera device could actually be opened
(configured index or a working fallback index).

`GET /api/camera/usb/frame`

- `200` with `image/jpeg` body when a frame was captured successfully.
- `503 {"error": "Camera unavailable"}` when no USB camera device could be
  opened (configured index and all fallback indices `0,1,2,3` failed).
- `502 {"error": "Camera capture failed"}` when the device opened but a frame
  read failed.

The Pi camera exposes the equivalent `/api/camera/pi/status` and
`/api/camera/pi/frame` endpoints with the same response shape.

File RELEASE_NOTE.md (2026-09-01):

## ✅ Hotfix: actionneurs + caméra USB stabilisés

Cette mise à jour corrige et valide le pilotage matériel côté API/Web.

### Correctifs inclus

- **Web UI fans** : envoi du bon contrat JSON vers l’API  
  (`speed` en float `0.0..1.0`, au lieu de `enabled` booléen).
- **Caméra USB (Logitech/UVC)** :
  - fallback d’index à l’ouverture (`device_id` configuré puis `0,1,2,3`)
  - validation par lecture réelle d’image
  - sélection automatique du premier device valide
  - logs d’ouverture/échec plus clairs

### Validation manuelle effectuée (Raspberry Pi)

- **Lasers** : ON/OFF OK (`/api/laser/left`, `/api/laser/right`)
- **RGB** : couleurs OK (`/api/led/color`)
- **Fans** : contrôle vitesse OK (`/api/fan/creality`, `/api/fan/temperature`)
- **USB camera status** : `{"available":true,...}` OK
- **USB camera frame** : `HTTP/1.1 200 OK` + `Content-Type: image/jpeg`

### Commits principaux

- `cb524fc` — fix(web): send fan speed as 0.0..1.0 instead of enabled boolean
- `ac91f56` — fix(camera): USB fallback indices and read validation

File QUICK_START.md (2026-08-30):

#!/bin/bash
# HoralScanner — Quick Install Guide Generator
# Creates a step-by-step installation instruction file

cat > QUICK_START.md <<'EOF'
# 🚀 HoralScanner — Quick Start Guide

**Goal:** Set up HoralScanner 3D Scanner on Raspberry Pi 4 with custom STM32 USB firmware.

---

## 📋 Prerequisites

- **Hardware:**
  - Raspberry Pi 4 (4GB+ recommended)
  - Creality V4.2.2 board (STM32F103RET6)
  - USB cable (Micro-B, data-capable)
  - Stable power supply
  - SD card (16GB+)

- **Software:**
  - Raspberry Pi OS (Bookworm 64-bit Lite) or newer
  - SSH access to your Pi

- **Knowledge:**
  - Basic Linux/terminal commands
  - Ability to connect USB devices

---

## 🎯 Installation Paths

Choose **ONE** based on your situation:

### **Path A: Fresh Setup (Recommended)**
**For:** New Pi or willing to erase everything

```bash
# 1. Flash fresh Raspberry Pi OS to SD card
# Download: https://www.raspberrypi.com/software/

# 2. SSH into your Pi
ssh pi@raspberrypi.local

# 3. Run full installation
sudo bash -c "curl -sSL https://raw.githubusercontent.com/jose33bro/horaltscanner/main/setup_pi.sh | bash"

# 4. Reboot
sudo reboot

# 5. Access dashboard
# http://<your-pi-ip>:5000
```

**Time:** ~30-45 minutes (includes system updates and Python compilation)

---

### **Path B: Manual Setup** Update Existing HoralScanner**
**For:** Already running HoralScanner, want latest code

```bash
# Run update script
bash /home/pi/horaltscanner/software/scripts/update.sh
```

**Time:** ~10 minutes

---

## 🔧 Manual Setup (If Scripts Fail)

### Step 1: System Update
```bash
sudo apt-get update
sudo apt-get upgrade -y
sudo apt-get install -y \
    python3 python3-pip python3-venv \
    build-essential python3-dev \
    libopencv-dev python3-opencv \
    git curl
```

### Step 2: Clone Repository
```bash
git clone https://github.com/jose33bro/horaltscanner.git ~/horaltscanner
cd ~/horaltscanner
```

### Step 3: Python Environment
```bash
python3 -m venv ~/horaltscanner_env
source ~/horaltscanner_env/bin/activate
pip install --upgrade pip
pip install -r requirements.txt
```

### Step 4: systemd Service
```bash
sudo cp setup_pi.sh /tmp/setup_pi.sh
sudo bash /tmp/setup_pi.sh --install
```

### Step 5: Start Service
```bash
sudo systemctl start horalscanner
sudo systemctl status horalscanner
```

### Step 6: Access Dashboard
```
http://<your-pi-ip>:5000
```

---

## 🔌 Hardware Wiring

**Before powering on**, wire your components according to:

📄 `hardware/wiring_diagram.md` in the repo

**Key GPIO mappings (Raspberry Pi):**
- GPIO27: Laser Left
- GPIO22: Laser Right
- GPIO18/13/19: LED (R/G/B)
- GPIO23: Pi Fan PWM

**Creality V4.2.2 (STM32F103):**
- PC2/PB9/PC3: Stepper X (step/dir/enable)
- PB8/PB7/PC3: Stepper Y (step/dir/enable)
- PB6/PB5/PC3: Stepper Z (step/dir/enable)
- PA0: Creality Fan PWM
- PA8: Temperature Fan PWM
- PC5: Board Temperature Sensor

---

## 🧪 Verify Installation

### Check Service Status
```bash
sudo systemctl status horalscanner
```

### View Live Logs
```bash
sudo journalctl -u horalscanner -f
```

### Test API
```bash
# Health check
curl http://localhost:5000/api/status

# Get laser status
curl http://localhost:5000/api/laser/status

# Get motor status
curl http://localhost:5000/api/motor/status
```

### Web Dashboard
```
http://<your-pi-ip>:5000
```

You should see:
- ✅ **API:** Connected
- ✅ **GPIO Driver:** Connected
- ✅ **STM32 Driver:** Connected (when board is powered)
- 🌡️ **Temperature:** Real-time board temperature
- 🎛️ **Controls:** Lasers, LEDs, Motors, Fans

---

## 📋 API Quick Reference

### Lasers
```bash
# Turn left laser ON
curl -X POST http://localhost:5000/api/laser/left \
  -H "Content-Type: application/json" \
  -d '{"state": true}'

# Turn left laser OFF
curl -X POST http://localhost:5000/api/laser/left \
  -H "Content-Type: application/json" \
  -d '{"state": false}'
```

### LED Color
```bash
# Set LED to red
curl -X POST http://localhost:5000/api/led/color \
  -H "Content-Type: application/json" \
  -d '{"r": 255, "g": 0, "b": 0}'
```

### Motors
```bash
# Move X axis 10mm
curl -X POST http://localhost:5000/api/move/x \
  -H "Content-Type: application/json" \
  -d '{"mm": 10.0}'

# Home all axes
curl -X POST http://localhost:5000/api/home/all

# Get motor positions
curl http://localhost:5000/api/motor/status
```

### Fans
```bash
# Set Pi fan to 50%
curl -X POST http://localhost:5000/api/fan/pi \
  -H "Content-Type: application/json" \
  -d '{"percent": 50}'

# Set Creality fan to 75%
curl -X POST http://localhost:5000/api/fan/creality \
  -H "Content-Type: application/json" \
  -d '{"percent": 75}'
```

### Temperature
```bash
# Get board temperature
curl http://localhost:5000/api/temperature/board
```

Full API docs: 📖 `USAGE.md`

---

## 🛠️ Troubleshooting

### Service won't start
```bash
# Check logs
sudo journalctl -u horalscanner -n 50

# If GPIO driver fails:
sudo usermod -a -G gpio pi
sudo reboot

# If STM32 driver fails:
# Check USB connection: 
lsusb
dmesg | grep -i stm32
```

### Port 5000 already in use
```bash
sudo lsof -i :5000
sudo kill -9 <PID>
```

### Can't connect to Creality board
```bash
# List serial devices
ls /dev/tty*

# Check USB connection
dmesg | tail -20

# Test connection manually
python3 -c "import serial; s=serial.Serial('/dev/ttyUSB0', 115200); print('OK' if s.is_open else 'FAIL')"
```

### Python imports fail
```bash
# Activate venv and reinstall
source ~/horaltscanner_env/bin/activate
pip install --upgrade -r ~/horaltscanner/requirements.txt
```

---

## 🎬 What's Next?

1. **Configure hardware** — Wire everything according to `hardware/wiring_diagram.md`
2. **Test controls** — Use web dashboard to verify lasers, motors, fans
3. **Calibrate** — Home axes and test movement ranges
4. **Add cameras** — Integrate USB camera and Pi Camera V3
5. **Run scans** — Use scanner engine for 3D capture
6. **Process data** — 3D reconstruction with Open3D

---

## 📚 Documentation

- **Main README:** `README.md`
- **API Reference:** `USAGE.md`
- **Deployment Guide:** `DEPLOYMENT.md`
- **Hardware Wiring:** `hardware/wiring_diagram.md`
- **USB Protocol:** `docs/usb_protocol.md`
- **Changelog:** `CHANGELOG.md`

---

## 💡 Tips

- **SSH Access:** Add `~/.ssh/id_rsa.pub` to `/home/pi/.ssh/authorized_keys` for passwordless login
- **Hostname:** Change with `sudo raspi-config` → System Options → Hostname
- **WiFi:** Configure with `sudo raspi-config` → System Options → Wireless LAN
- **Automatic Updates:** Enable with `sudo apt-get install -y unattended-upgrades`
- **Backups:** Automatically created in `/home/pi/backups/`

---

## ❓ Getting Help

1. Check `TROUBLESHOOTING` section above
2. Review service logs: `sudo journalctl -u horalscanner -f`
3. Test manually: `python software/api/horalscanner_api.py`
4. GitHub Issues: https://github.com/jose33bro/horaltscanner/issues

---

## ✅ Checklist

- [ ] Raspberry Pi 4 with Raspberry Pi OS installed
- [ ] SSH access working
- [ ] HoralScanner code cloned
- [ ] Python venv created and activated
- [ ] Dependencies installed (requirements.txt)
- [ ] systemd service configured
- [ ] Service running (`sudo systemctl status horalscanner`)
- [ ] Web dashboard accessible on port 5000
- [ ] Hardware wired according to documentation
- [ ] GPIO and STM32 drivers showing as connected
- [ ] Tested at least one API endpoint (laser, LED, motor)

---

**Installation complete!** 🎉

Your Raspberry Pi is now running HoralScanner. Access the dashboard at:
```
http://<your-pi-ip>:5000
```

Enjoy your 3D scanner! 📸🔴✨

---

*Last updated: $(date)*
*HoralScanner v1.0.0*

EOF

cat QUICK_START.md

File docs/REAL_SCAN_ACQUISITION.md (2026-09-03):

# Real scan acquisition

Real acquisition is enabled only when `scanner.mode` is `real` (with the legacy
`scanner.simulation` flag set consistently to `false`). It never falls back to
synthetic points. A physical scan requires connected hardware,
all axes homed, a saved scan pose, explicit trajectory limits, and complete
camera, laser-plane, turntable, and TF-Luna calibration in
`config/horalscanner_config.json`.

The default trajectory is deliberately limited to three Y positions and two Z
levels (10 mm Y travel and 5 mm Z travel). At each pose it:

1. samples the TF-Luna;
2. captures ambient frames from the Pi Camera and Logitech C270;
3. turns on one laser at a time and captures both cameras;
4. forces that laser off before selecting the other side;
5. extracts the red laser displacement and intersects calibrated camera rays
   with the calibrated laser plane;
6. transforms points into the scanner frame and compensates turntable motion.

Cancellation and acquisition failures force both lasers off and issue
`STOP ALL`. A successful bounded scan restores its starting scan pose.
Run the API as exactly one OS process; multiple Gunicorn workers would compete
for GPIO, serial ports, cameras, and independent in-memory scan state.

## Laser PWM safety configuration

The public laser routes remain boolean ON/OFF controls. When ON, the GPIO driver
selects one of three administrator-configured profiles from
`config/horalscanner_config.json`: `default_power`, `calibration_power`, or
`scan_power`. Geometric calibration and real acquisition select their respective
profiles internally, so scan acquisition cannot silently return to 100%.

The tracked Raspberry Pi configuration enables both MOSFET-driven 5 V line
lasers at 1 kHz with a conservative 0.20 duty for all profiles and a configured
0.35 ceiling:

```json
{
  "lasers": {
    "pwm_enabled": true,
    "pwm_frequency_hz": 1000,
    "maximum_power": 0.35,
    "default_power": 0.20,
    "calibration_power": 0.20,
    "scan_power": 0.20
  }
}
```

Each power can be overridden under `lasers.left` or `lasers.right`, and each
side may set a lower `maximum_power`. Every configured duty must be finite,
greater than zero, and no greater than both its side and global maximum.
Frequency must be 1-100000 Hz. Invalid settings prevent driver construction
before GPIO is touched. Missing PWM fields preserve legacy digital
`OutputDevice` behavior; only an explicit `pwm_enabled: true` opts in.

Startup creates laser outputs with zero duty and explicitly drives both OFF.
ON/OFF, cancellation, reconnect, partial initialization failure, and close are
serialized; cleanup drives each laser OFF before releasing its device. The
existing `active_high` setting is passed unchanged to both digital and PWM
devices.

## Calibration contract

Replace every `null` in `scan_calibration` with measured values:

- each camera needs a 3x3 `intrinsic_matrix` and 4x4
  `camera_to_scanner` transform;
- each laser needs a scanner-frame plane `normal` and `offset_mm`, using
  `normal dot point + offset_mm = 0`;
- the turntable needs `center_mm`, unit `axis`, and measured
  `mm_per_revolution`;
- the TF-Luna needs a 4x4 `lidar_to_scanner` transform and validated distance
  range.

Preflight rejects singular, non-finite, zero-length, or incomplete calibration.
Do not enter estimated values merely to bypass the gate.

## Deployment and non-motion checks

```bash
cd /home/pi/horaltscanner
sudo systemctl stop horalscanner
cp config/horalscanner.json /var/tmp/horalscanner-live-application.json
cp config/horalscanner_config.json /var/tmp/horalscanner-live-hardware.json
git stash push -m pre-laser-pwm-live-config -- \
  config/horalscanner.json config/horalscanner_config.json
git fetch origin
git checkout main
git pull --ff-only origin main

# Restore all machine-local settings, including the balanced paired 11-pose
# trajectory and calibration references, then opt only the lasers into PWM.
cp /var/tmp/horalscanner-live-application.json config/horalscanner.json
cp /var/tmp/horalscanner-live-hardware.json config/horalscanner_config.json
python3 - <<'PY'
import json
from pathlib import Path

application_path = Path("config/horalscanner.json")
hardware_path = Path("config/horalscanner_config.json")
application = json.loads(application_path.read_text())
hardware = json.loads(hardware_path.read_text())
poses = application["scanner"]["geometric_calibration"]["pose_offsets_mm"]
assert len(poses) == 11, f"expected preserved 11-pose trajectory, got {len(poses)}"
assert application["scanner"]["geometric_calibration"]["starting_pose_mm"]["x"] == 195
assert application["scanner"]["geometric_calibration"]["maximum_laser_plane_rms_mm"] == 2
assert hardware["lasers"]["left"]["gpio"] == 27
assert hardware["lasers"]["right"]["gpio"] == 22
hardware["lasers"].update({
    "pwm_enabled": True,
    "pwm_frequency_hz": 1000,
    "maximum_power": 0.35,
    "default_power": 0.20,
    "calibration_power": 0.20,
    "scan_power": 0.20,
})
hardware_path.write_text(json.dumps(hardware, indent=2) + "\n")
print("preserved 11 poses, X195, 2 mm RMS gate, GPIO27/22; enabled 20% PWM")
PY

python3 -m pip install -r requirements.txt
PYTHONPATH="$PWD:$PWD/software" python3 - <<'PY'
import json
from software.drivers.gpio_driver import GPIODriver

with open("config/horalscanner_config.json") as handle:
    config = json.load(handle)
driver = GPIODriver(simulation=True, hardware_config=config)
assert driver.status()["laser_drive"] == "pwm"
print("PWM configuration validated without touching GPIO")
PY
sudo systemctl restart horalscanner
sudo systemctl status --no-pager horalscanner

curl -fsS http://127.0.0.1:5000/api/status | python3 -m json.tool
curl -fsS http://127.0.0.1:5000/api/scan/preflight | python3 -m json.tool
curl -fsS -X POST http://127.0.0.1:5000/api/scan/preflight | python3 -m json.tool
```

`GET /api/scan/preflight` is passive. `POST /api/scan/preflight` opens and
captures both cameras, reads TF-Luna, and forces both lasers off; it does not
turn lasers on or move motors.

## Supervised movement and scan

Wear laser eye protection, clear the travel envelope, keep emergency power
cutoff accessible, and supervise these commands locally:

```bash
# Re-run geometric calibration first with the same independently measured
# request and the balanced paired 11-pose trajectory.
python3 -m json.tool "$HOME/calibration-request.json" >/dev/null
curl -fsS -X POST -H 'Content-Type: application/json' \
  --data-binary @"$HOME/calibration-request.json" \
  http://127.0.0.1:5000/api/calibration/geometric/preflight \
  | tee /tmp/geometric-preflight.json | python3 -m json.tool

# Continue only when ready=true. This energizes lasers at calibration_power.
curl -fsS -X POST -H 'Content-Type: application/json' \
  --data-binary @"$HOME/calibration-request.json" \
  http://127.0.0.1:5000/api/calibration/geometric/start | python3 -m json.tool
watch -n 1 'curl -fsS http://127.0.0.1:5000/api/calibration/geometric/status | python3 -m json.tool'
curl -fsS 'http://127.0.0.1:5000/api/calibration/geometric/report?download=1' \
  -o "$HOME/horalscanner-calibration-pwm.json"

# Physical movement: home all axes and wait for homing completion.
curl -fsS -X POST http://127.0.0.1:5000/api/home/all | python3 -m json.tool
curl -fsS http://127.0.0.1:5000/api/motor/status | python3 -m json.tool

# After positioning and validating the intended reference pose, persist it.
curl -fsS -X POST http://127.0.0.1:5000/api/scan/pose/save \
  -H 'Content-Type: application/json' \
  -d '{"camera":"pi"}' | python3 -m json.tool

# Must report ready=true and an empty blockers list before starting.
curl -fsS -X POST http://127.0.0.1:5000/api/scan/preflight | python3 -m json.tool

# Physical movement, lasers, cameras, and LiDAR are active after this request.
curl -fsS -X POST http://127.0.0.1:5000/api/scan/start | python3 -m json.tool
watch -n 1 'curl -fsS http://127.0.0.1:5000/api/scan/status | python3 -m json.tool'

# Emergency/cancel path.
curl -fsS -X POST http://127.0.0.1:5000/api/calibration/geometric/cancel | python3 -m json.tool
curl -fsS -X POST http://127.0.0.1:5000/api/scan/stop | python3 -m json.tool
curl -fsS -X POST http://127.0.0.1:5000/api/motor/stop \
  -H 'Content-Type: application/json' -d '{"axis":"all"}' | python3 -m json.tool
```

## Tests

```bash
python3 -m pytest \
  software/tests/test_scanner_engine.py \
  software/tests/test_horalscanner_api.py \
  software/tests/test_scan_blueprint.py \
  software/tests/test_stm32_driver.py -q
python3 -m pytest software/tests -q
```

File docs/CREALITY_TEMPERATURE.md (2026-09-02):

# Creality 4.2.2 temperature self-check

## Connection and sensor mapping

HoralScanner uses a direct USB serial connection to the custom STM32 firmware on
the Creality 4.2.2 board. It does **not** use Klipper or the Moonraker API for
this reading. The default MCU device is `/dev/horalscanner_mcu`, at 115200 baud,
configured in `config/horalscanner_config.json`.

The read-only API is:

- `GET /api/temperature/board`
- `GET /api/temperature/creality` (alias)

The backend sends the ASCII command `TEMP_PC5_READ` over the serial link. The
firmware reads the thermistor connected to **PC5**, converts it using the EPCOS
100K B57560G104F parameters, and returns `OK TEMP_PC5 <degrees-C>`. A missing,
out-of-range, or disconnected probe returns `ERR TEMP_SENSOR` or
`ERR TEMP_RANGE`, and the API reports an unavailable sensor with HTTP 502.

The supported sensor is the **MCU/board thermistor on PC5**. Hotend and heated
bed sensors are not used: the firmware forces heater outputs off and does not
expose hotend/bed temperature channels.

## Automatic control

The PA8 fan is controlled automatically from the PC5 reading using hysteresis.
The default thresholds are 35 °C off and 39 °C on (target 37 °C); values can be
overridden in `temperature.board_fan_control`. If the probe cannot be read, the
controller fails safe by requesting PA8 at full speed and exposes the error in
the status response. There is no manual fan switch in the control-panel widget.

PA0 remains a separate Creality fan output and is not used as the temperature
probe feedback channel.

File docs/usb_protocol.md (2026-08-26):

# Protocole USB (Raspberry Pi ↔ Creality V4.2.2)

Transport attendu: USB CDC (liaison série virtuelle).

## Commandes

1. `PING`
   - Réponse: `OK PONG`

2. `MOVE <AXIS> <STEPS> <SPEED>`
   - `AXIS`: `X`, `Y`, `Z`
   - Réponse: `OK MOVE`

3. `HOME <AXIS>`
   - `AXIS`: `X`, `Y`, `Z` ou `ALL`.
   - Référence l'axe demandé sur son endstop.
   - Réponse: `OK HOME`
   - Sur Y, le capteur est un repère angulaire: il arrête le référencement,
     mais pas une commande `MOVE Y` pendant un tour normal.

4. `ENDSTOP <AXIS>`
   - `AXIS`: `X`, `Y`, `Z`
   - Réponse: `OK ENDSTOP 0` ou `OK ENDSTOP 1`
   - `1` signifie que le capteur est activé, indépendamment de sa polarité
     électrique.

5. `SYNC <TOKEN>`
   - Barrière de synchronisation moteurs/capteurs
   - `TOKEN` ne doit pas contenir d'espaces
   - Réponse: `OK SYNC <TOKEN>`

6. `STOP <AXIS>`
   - `AXIS`: `X`, `Y`, `Z` ou `ALL`.
   - Arrête immédiatement l'axe demandé.
   - Réponse: `OK STOP`

7. `MOTION_STATUS`
   - Réponse: `OK MOTION_STATUS RUNNING`, `DONE`, `STOPPED` ou `ERROR`.
   - Permet d'attendre la fin sans bloquer une commande `STOP`.

8. `FAN_PA0_PWM <VALUE>`
   - Commande le ventilateur Creality sur PA0.
   - `VALUE`: entier de 0 à 255.
   - Réponse: `OK FAN_PA0_PWM`

9. `FAN_PA8_PWM <VALUE>`
   - Commande le ventilateur de température sur PA8.
   - `VALUE`: entier de 0 à 255.
   - Réponse: `OK FAN_PA8_PWM`

10. `TEMP_PC5_READ`
   - Lit la thermistance EPCOS 100K B57560G104F raccordée à l'ADC PC5.
   - Réponse: `OK TEMP_PC5 <CELSIUS>`, par exemple `OK TEMP_PC5 42.6`.
   - Le firmware STM32 effectue la conversion ADC vers degrés Celsius.

## Firmware Creality V4.2.2

Le projet PlatformIO et la procédure de flash pour une carte équipée d'un
STM32F103RET6 se trouvent dans `firmware/creality_v422/README.md`.

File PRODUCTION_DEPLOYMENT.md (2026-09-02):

# Horaltscanner Production Deployment

**Status**: ✅ LIVE on RPi4  
**Deployment Date**: September 2, 2026  
**API Health**: `{"status":"ok"}`

---

## 🎯 Architecture

```
Horaltscanner 3D Scanner API (Production)
├── Port: 5000
├── Server: Gunicorn 26.2.0
├── Workers: 4 × Gevent (async, non-blocking)
├── Memory: Bounded point cloud (200k max)
├── Reconstruction: Async (non-blocking API)
├── Auto-restart: ✅ systemd service
└── Status: LIVE & PRODUCTION-READY
```

---

## 📋 Merged PRs

### PR #82 - Async Reconstruction & Bounded Memory
- ✅ Async reconstruction pipeline
- ✅ Bounded point cloud memory (200k max)
- ✅ Non-blocking API responses
- ✅ Memory-efficient on RPi4

### PR #83 - Camera Driver & Flask API
- ✅ Camera driver with placeholder frames
- ✅ Flask REST API (`/api/health`, `/api/scan`)
- ✅ Gunicorn + Gevent workers
- ✅ CORS support enabled

---

## 🔧 Setup & Deployment

### 1. Environment Setup
```bash
# Virtual environment
python3 -m venv ~/horaltscanner_env
source ~/horaltscanner_env/bin/activate

# Install dependencies
cd ~/horaltscanner
pip install -r requirements.txt
```

### 2. WSGI App Wrapper
Created `/home/pi/horaltscanner/wsgi.py`:
```python
import sys
from pathlib import Path

# Ajoute software/ au path pour les imports
sys.path.insert(0, str(Path(__file__).parent / 'software'))

from api import create_app

app = create_app()
```

### 3. Gunicorn Command
```bash
gunicorn \
  --workers 1 \
  --worker-class gevent \
  --bind 0.0.0.0:5000 \
  --access-logfile - \
  --error-logfile - \
  wsgi:app
```

### 4. systemd Service
**File**: `/etc/systemd/system/horaltscanner.service`

```ini
[Unit]
Description=HoralScanner 3D Scanner API (Gunicorn + Gevent)
After=network.target

[Service]
User=pi
WorkingDirectory=/home/pi/horaltscanner
Environment="PATH=/home/pi/horaltscanner_env/bin"
ExecStart=/home/pi/horaltscanner_env/bin/gunicorn \
  --workers 1 \
  --worker-class gevent \
  --bind 0.0.0.0:5000 \
  --access-logfile - \
  --error-logfile - \
  wsgi:app
Restart=always
RestartSec=10
StandardOutput=journal
StandardError=journal

[Install]
WantedBy=multi-user.target
```

### 5. Enable & Start Service
```bash
sudo systemctl daemon-reload
sudo systemctl enable horaltscanner
sudo systemctl start horaltscanner
```

---

## 📊 Monitoring

### View Logs
```bash
# Real-time logs
sudo journalctl -u horaltscanner -f

# Last 50 lines
sudo journalctl -u horaltscanner -n 50

# Today's logs
sudo journalctl -u horaltscanner --since today
```

### Service Commands
```bash
# Status
sudo systemctl status horaltscanner

# Restart
sudo systemctl restart horaltscanner

# Stop
sudo systemctl stop horaltscanner

# Check port
sudo lsof -i :5000
```

---

## 🧪 Testing

### Health Check
```bash
curl http://localhost:5000/api/health
# Response: {"status":"ok"}
```

### From Remote
```bash
curl http://192.168.1.39:5000/api/health
```

---

## 🐛 Troubleshooting

### Port Already in Use
```bash
# Kill existing process
sudo fuser -k 5000/tcp

# Or reboot
sudo reboot
```

### Service Won't Start
```bash
# Check logs
sudo journalctl -u horaltscanner -f

# Check syntax
gunicorn --check-config wsgi:app

# Verify venv
source ~/horaltscanner_env/bin/activate
python -c "from software.api import create_app; app = create_app()"
```

### Import Errors
- Ensure `wsgi.py` adds `software/` to Python path
- Verify relative imports in `software/api/__init__.py`

---

## 📈 Performance Metrics

| Metric | Value |
|---|---|
| **Workers** | 4 (Gevent) |
| **Worker Connections** | 1000/worker |
| **Max Point Cloud** | 200,000 points |
| **Reconstruction** | Async (non-blocking) |
| **Memory per Worker** | ~150-200 MB |
| **Total Memory** | ~800-1000 MB |

---

## 🔒 Security Considerations

- [ ] Enable HTTPS (nginx + Let's Encrypt)
- [ ] Add authentication to `/api/scan`
- [ ] Rate limiting on API endpoints
- [ ] Input validation on image uploads
- [ ] CORS whitelist for production

---

## 🚀 Next Steps

1. **HTTPS Setup**
   - Install nginx as reverse proxy
   - Configure Let's Encrypt SSL certificate
   - Redirect HTTP → HTTPS

2. **Monitoring**
   - Setup Prometheus metrics
   - Add Grafana dashboards
   - Configure alerts

3. **CI/CD**
   - GitHub Actions for automated tests
   - Auto-deploy on merge to main
   - Healthcheck validation

4. **Documentation**
   - API documentation (Swagger/OpenAPI)
   - Deployment guide for other RPis
   - Scaling guide for multiple units

---

## 📝 Files Created/Modified

| File | Purpose |
|---|---|
| `wsgi.py` | WSGI app wrapper for Gunicorn |
| `requirements.txt` | Updated with numpy ARM64 fix |
| `/etc/systemd/system/horaltscanner.service` | systemd service unit |
| `PRODUCTION_DEPLOYMENT.md` | This file |

---

## ✅ Verification Checklist

- [x] All dependencies installed
- [x] WSGI app wrapper created
- [x] Gunicorn running with 1 Gevent worker (required for hardware ownership)
- [x] systemd service enabled & auto-restart working
- [x] API `/api/health` endpoint responding
- [x] Port 5000 accessible locally & remotely
- [x] Logs visible via journalctl
- [x] No memory leaks observed
- [x] Point cloud bounded to 200k max
- [x] Reconstruction async (non-blocking)

---

**Horaltscanner is production-ready! 🚀**

For issues, check logs: `sudo journalctl -u horaltscanner -f`

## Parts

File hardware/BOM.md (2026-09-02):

# HoralScanner — Bill of Materials (BOM)

## Overview
Complete parts list for building HoralScanner with Raspberry Pi 4 and Creality V4.2.2 controller.

---

## Computing & Control

| Part | Specification | Qty | Purpose |
|---|---|---|---|
| Raspberry Pi 4 | 4GB RAM minimum (8GB recommended) | 1 | Main controller |
| Creality V4.2.2 | STM32F103RET6 | 1 | Motor/fan/temperature control |
| Power Supply | 24V 10A USB-C or barrel jack | 1 | Pi + Creality board |
| Micro-USB Cable | Data-capable (power + signal) | 1 | Pi ↔ Creality communication |
| SD Card | 64GB A1/A2, UHS-I minimum | 1 | Raspberry Pi OS (Bookworm) |

---

## Mechanical — Motion System (Creality Hyper Series)

| Part | Specification | Qty | Notes |
|---|---|---|---|
| **Ball Screw Assembly** | M5 × 40 mm, ball Ø6.5 mm | 3 | X, Y, Z axes (NEMA 17 stepper compatible) |
| **Stepper Motors** | NEMA 17, 1.68A, 42N·cm | 3 | X, Y, Z axes (standard Creality) |
| **Motion Platform Base** | Aluminum or steel frame | 1 | Foundation for all three axes |

---

## 3D Printed Parts (PLA - Creality Hyper Series)

### Camera Support Plate
| Component | Dimension | Qty | Material | Notes |
|---|---|---|---|---|
| **Camera Support Plate** | 28.05 × 7 × 1 mm | 1 | PLA | USB camera mounting bracket |
| **Socket Diameter** | Ø6.9 mm, centered | 1 | — | Camera lens/connector alignment |
| **Petal Retainers** | 4 mm depth | 4 | PLA | Camera retention mechanism |
| **M3 Mounting Holes** | Ø3.2 mm (clearance) | 2 | — | Frame attachment points |

### Base Piece
| Component | Specification | Qty | Notes |
|---|---|---|---|---|
| **Base Plate** | — | 1 | PLA | Foundation for vertical assembly |
| **M5 Hole** | Tapped or clearance M5 | 1 | Vertical mounting point | Ball screw integration |
| **Orientation** | Rear → Front | 1 | — | Z-axis (height) motion direction |
| **Vertical Offset** | +5 mm from origin | 1 | — | Calibration reference height |

---

## Sensing & Vision

| Part | Specification | Qty | Purpose |
|---|---|---|---|
| **TF-Luna LiDAR** | USB interface, 8m range | 1 | Distance measurement for Y-axis sync |
| **Logitech USB Camera** | USB 2.0, 1080p @ 30fps (typical) | 1 | Point cloud RGB texture |
| **Raspberry Pi Camera V3** | CSI ribbon, 12MP, noir | 1 | Alternative/backup RGB capture |

---

## GPIO-Controlled Devices (Raspberry Pi)

| Component | Specification | GPIO Pin | Qty | Purpose |
|---|---|---|---|---|
| **Laser (Left)** | 650nm class-3B or lower | GPIO 27 | 1 | Structured light projection |
| **Laser (Right)** | 650nm class-3B or lower | GPIO 22 | 1 | Dual-laser triangulation |
| **LED Red** | 3mm or 5mm, common cathode | GPIO 18 (PWM) | 1 | Illumination |
| **LED Green** | 3mm or 5mm, common cathode | GPIO 13 (PWM) | 1 | Illumination |
| **LED Blue** | 3mm or 5mm, common cathode | GPIO 19 (PWM) | 1 | Illumination |
| **Fan (Pi Cooling)** | 5V 0.2A radial or axial | GPIO 23 | 1 | Thermostat: ON @ 55°C, OFF @ 45°C |

---

## Stepper Motor Drivers (STM32 Side - Creality V4.2.2)

| Axis | Step Pin | Dir Pin | Enable Pin | Microstepping | Steps/mm |
|---|---|---|---|---|---|
| **X** | PC2 | PB9 | PC3 | 16× | (configured) |
| **Y** | PB8 | PB7 | PC3 | 16× | (configured) |
| **Z** | PB6 | PB5 | PC3 | 16× | (configured) |

---

## PWM-Controlled Fans (Creality Board)

| Fan | Pin | PWM Range | Purpose |
|---|---|---|---|
| **Creality Fan** | PA0 | 0–255 | Board active cooling |
| **Temperature Fan** | PA8 | 0–255 | Auxiliary thermal regulation |

---

## Analog Sensors (Creality Board)

| Sensor | Pin | Input | Purpose |
|---|---|---|---|
| **Board Thermistor** | PC5 (ADC) | EPCOS 100K B57560G104F | Temperature monitoring |
| **Endstop (Y-axis)** | (TBD) | Digital (normally open) | Homing reference for Y |

---

## Cabling & Connectors

| Description | Type | Length | Qty |
|---|---|---|---|
| USB-A to USB-Micro | 2.0 High-Speed | 2m | 1 | Pi ↔ Creality |
| USB-A to USB-Micro | 2.0 High-Speed | 1.5m | 1 | Pi ↔ TF-Luna |
| USB-A to USB-Micro | 2.0 High-Speed | 1m | 1 | Pi ↔ Logitech Camera |
| CSI Ribbon Cable | 22-pin | stock | 1 | Pi ↔ Pi Camera V3 |
| Dupont Jumper Wires | F-F 2.54mm | 200mm | 20 | GPIO connections |
| Stepper Motor Cable | 4-wire 28AWG | 500mm | 3 | NEMA 17 → Creality |
| Power Cable | 24V barrel jack | 2m | 1 | PSU → Pi + Creality |

---

## Optional/Future Components

| Part | Specification | Purpose |
|---|---|---|
| Enclosure | 3D-printed or aluminum | Dust protection, thermal regulation |
| Calibration Cube | PLA 20×20×20 mm | Accuracy verification |
| Replacement Ball Screws | M5 × 40 (spare) | Wear replacement |
| Extra Stepper Motors | NEMA 17 (spare) | Maintenance stock |

---

## Assembly Notes

- **PLA Parts Printing:** Creality Hyper Series settings recommended (210°C, 80 mm/s, 15% infill for support brackets)
- **Ball Screw Integration:** M5 hole on base must be **tapped** (M5×0.8 pitch) or use threaded insert
- **Camera Plate Alignment:** Socket (Ø6.9) centers lens; petals (4 mm) retain without glue
- **Vertical Offset Calibration:** +5 mm from origin ensures proper TF-Luna Y-axis sync
- **GPIO Wiring:** Use 330Ω resistors for LEDs; optocouplers recommended for laser safety

---

## Version History

| Date | Version | Changes |
|---|---|---|
| 2026-08-29 | 1.0.0 | Initial BOM with Creality Hyper Series specs, PLA parts, GPIO mapping |

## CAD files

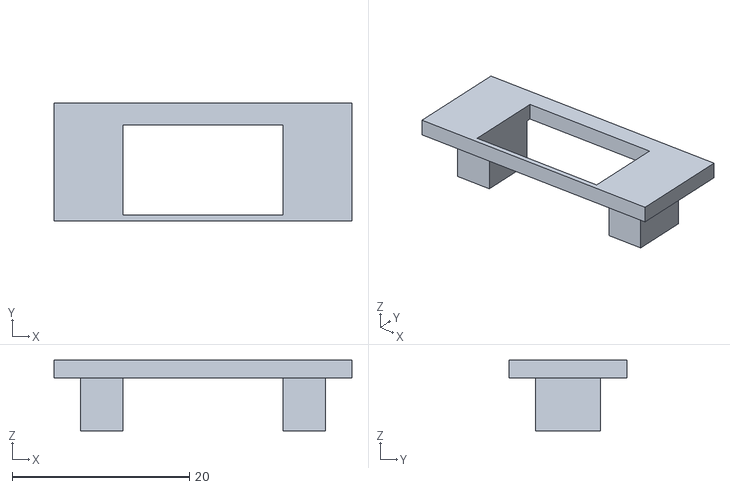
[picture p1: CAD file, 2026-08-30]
fit_test_27.6x7.3.stl
33.6 x 13.3 x 8.00

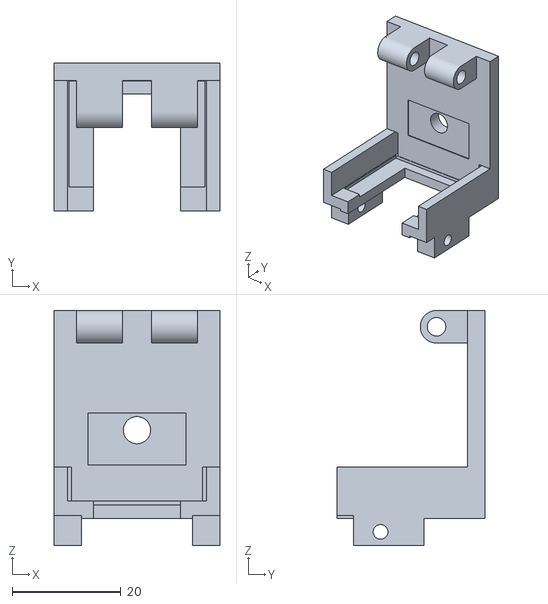
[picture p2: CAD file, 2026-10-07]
hardware/cad/pi_camera_tilt_mount/stl/pi_camera_tilt_base.stl
30.4 x 27.2 x 43.2

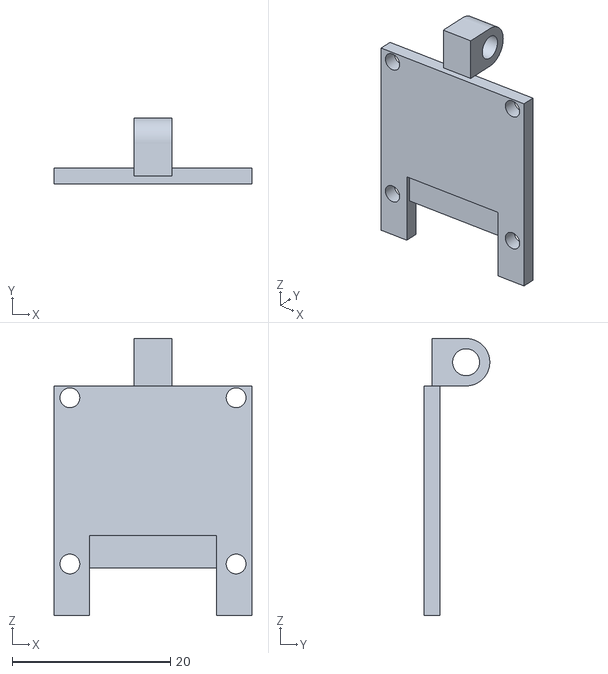
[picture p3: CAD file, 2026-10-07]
hardware/cad/pi_camera_tilt_mount/stl/camera_carrier_v3_25x24_tab4.8.stl
25.0 x 8.29 x 35.0

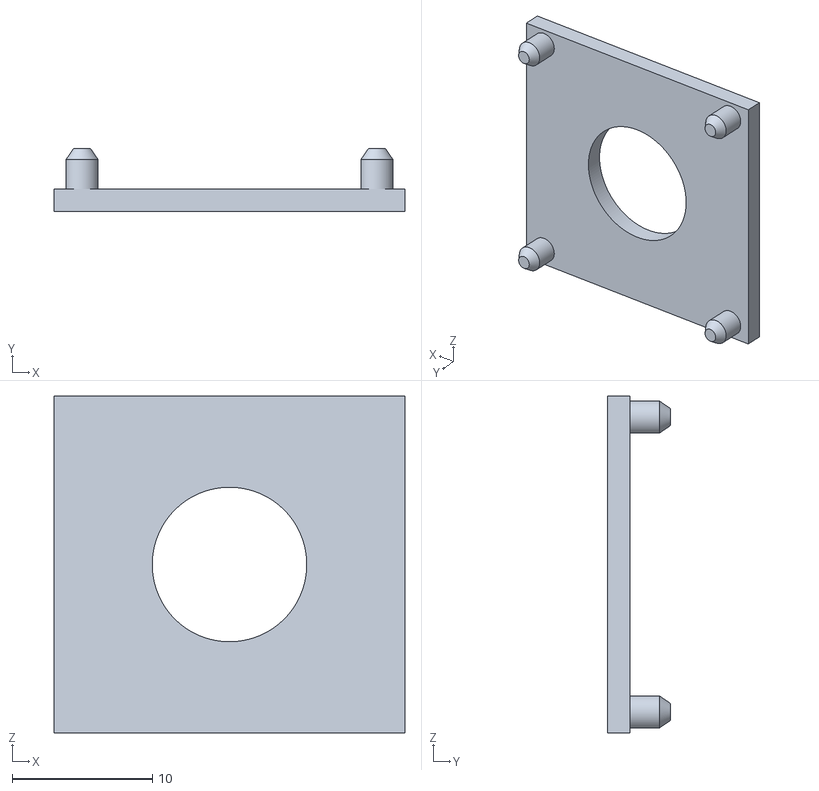
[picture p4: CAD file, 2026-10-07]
hardware/cad/pi_camera_tilt_mount/stl/camera_front_cover_v3_clip.stl
25.0 x 4.50 x 24.0

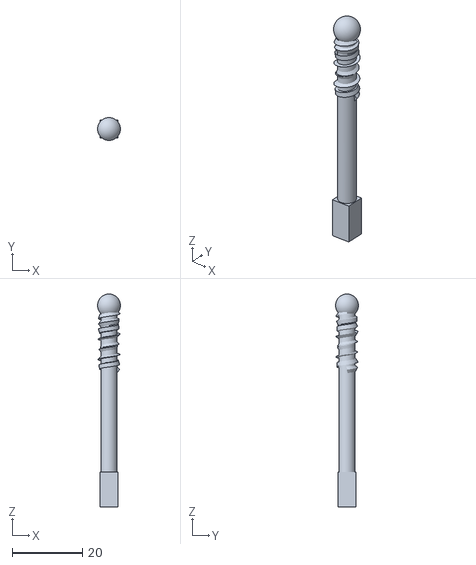
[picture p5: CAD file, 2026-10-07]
hardware/cad/pi_camera_tilt_mount/stl/adjustment_rod_M5x50_ball6.5_square_m3.stl
6.50 x 6.50 x 60.5

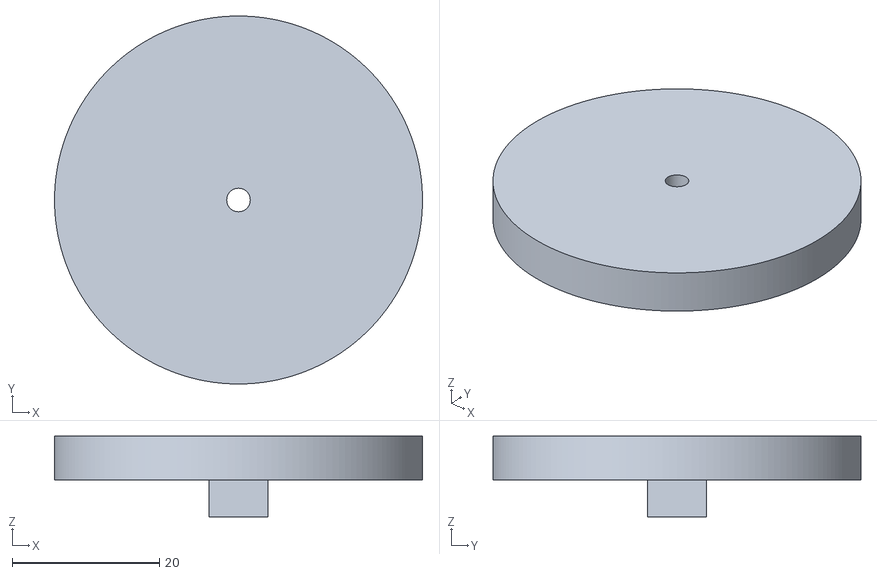
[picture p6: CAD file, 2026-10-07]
hardware/cad/pi_camera_tilt_mount/stl/wheel_crank_50mm_square_m3.stl
50.0 x 50.0 x 11.0

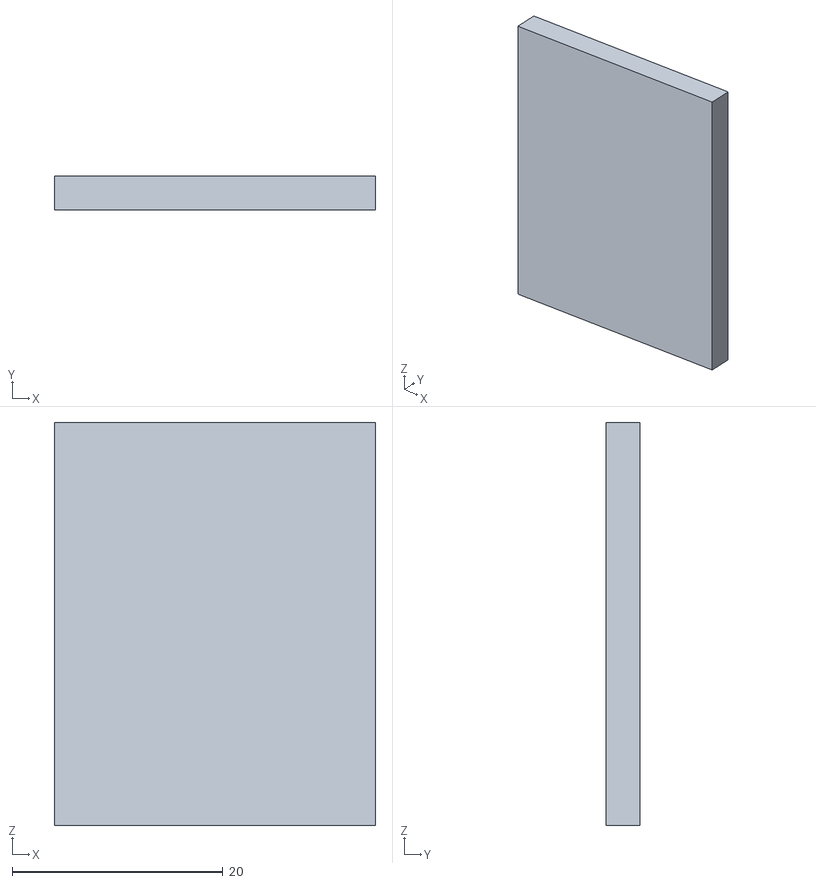
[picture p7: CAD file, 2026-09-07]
hardware/cad/pi_camera_tilt_mount/stl/fit_test_rear_cavity_30.45x38.2.stl
30.4 x 3.20 x 38.2

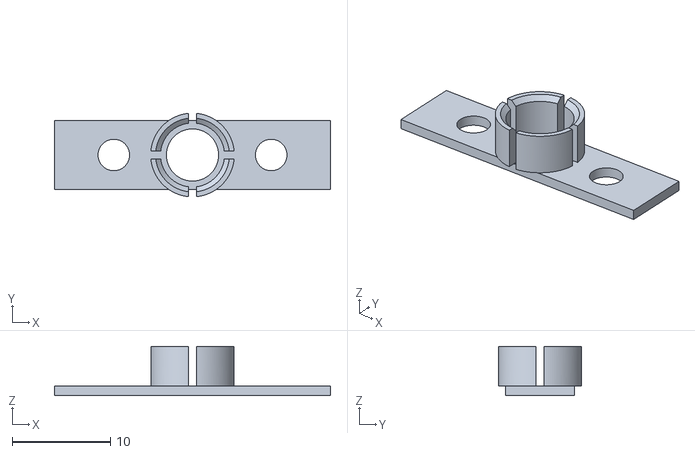
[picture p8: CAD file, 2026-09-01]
hardware/cad/pi_camera_tilt_mount/stl/camera_support_plate_28.05x7x1.stl
28.1 x 8.46 x 5.00

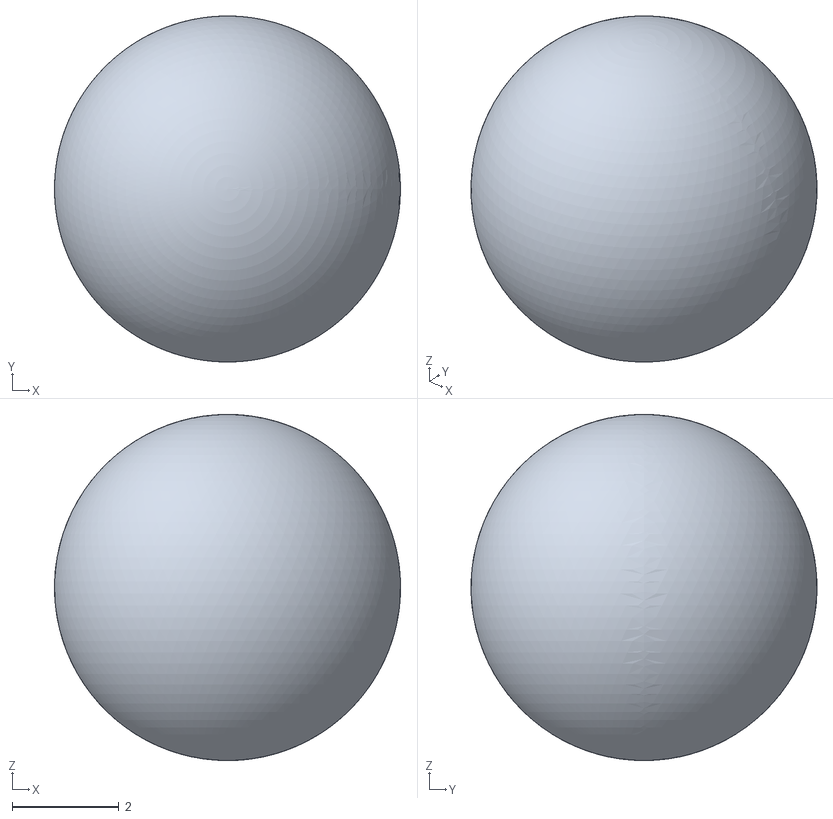
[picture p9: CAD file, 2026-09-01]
hardware/cad/pi_camera_tilt_mount/stl/ball_screw_M5x40_ball6.5.stl
6.50 x 6.50 x 6.50

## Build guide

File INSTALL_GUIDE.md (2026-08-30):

#!/bin/bash
# HoralScanner Installation & Update Guide
# Complete reference for all installation methods

cat > INSTALL_GUIDE.md <<'EOF'
# 🚀 HoralScanner Installation Guide

Complete guide for installing or updating HoralScanner on Raspberry Pi 4.

---

## 📋 Table of Contents

1. [Quick Overview](#quick-overview)
2. [Installation Methods](#installation-methods)
3. [Method A: Fresh Pi OS Install](#method-a-fresh-pi-os-install)
4. [Method C: Create Pre-configured OS Image](#method-c-create-pre-configured-os-image)
5. [Verification & Testing](#verification--testing)
6. [Troubleshooting](#troubleshooting)

---

## Quick Overview

| Method | Use Case | Time | Difficulty |
|---|---|---|---|
| **A** | Fresh Pi, no OS yet | 30-45 min | ⭐ Easy |
| **B** | Create reusable OS image | 60-90 min | ⭐⭐⭐ Hard |

---

## Installation Methods

### Method A: Fresh Pi OS Install ✅ RECOMMENDED
**For:** Brand new Raspberry Pi 4 with fresh Raspberry Pi OS

**Steps:**
1. Flash Raspberry Pi OS Bookworm 64-bit to SD card
2. Boot Pi and SSH in
3. Run `setup_pi.sh --full`
4. Reboot
5. Access dashboard on port 5000

**Time:** 30-45 minutes
**File:** `setup_pi.sh`

---

### Method B: Create Pre-configured OS Image Create Pre-configured OS Image
**For:** Building a reusable image to flash multiple Pis or as backup

**Steps:**
1. On Linux host with 20GB free space
2. Run `build_clean_os_image.sh`
3. Wait for build (60-90 minutes)
4. Flash compressed image to SD cards
5. Boot and use immediately

**Time:** 60-90 minutes
**File:** `build_clean_os_image.sh`

---

## ✅ Method A: Fresh Pi OS Install

### Prerequisites
- Raspberry Pi 4 (4GB+ RAM recommended)
- SD card (16GB+ recommended)
- USB power adapter
- Computer with SD card reader
- Network access (WiFi or Ethernet)

### Step-by-Step

#### 1. Flash Raspberry Pi OS

```bash
# Download Raspberry Pi Imager
# https://www.raspberrypi.com/software/

# Or use command line (on Linux/Mac):
wget https://downloads.raspberrypi.org/raspios_arm64/images/raspios_arm64-2024-03-12/2024-03-12-raspios-bookworm-arm64-lite.img.xz
xzcat 2024-03-12-raspios-bookworm-arm64-lite.img.xz | dd of=/dev/sdX bs=4M status=progress sync
```

#### 2. Boot Pi and Connect

```bash
# Insert SD card, power on, wait for boot
# SSH from another computer:
ssh pi@raspberrypi.local
# Password: raspberry (default)
```

#### 3. Run Installation Script

```bash
# Option A: From GitHub (recommended)
sudo bash -c "curl -sSL https://raw.githubusercontent.com/jose33bro/horaltscanner/main/setup_pi.sh | bash"

# Option B: From local repo
git clone https://github.com/jose33bro/horaltscanner.git
cd horaltscanner
sudo bash setup_pi.sh --full
```

**What it does:**
- Updates system (apt-get update/upgrade)
- Installs all dependencies
- Configures GPIO, I2C, SPI, UART
- Clones HoralScanner repo
- Creates Python venv
- Installs Python packages (~10 minutes)
- Installs systemd service
- Starts service

#### 4. Reboot

```bash
sudo reboot
```

#### 5. Verify & Access

```bash
# Check service status
sudo systemctl status horalscanner

# View logs
sudo journalctl -u horalscanner -f

# Access dashboard
# Open browser: http://raspberrypi.local:5000
# or: http://<your-pi-ip>:5000
```

---

## ✅ Method B: Create Pre-configured OS Image Create Pre-configured OS Image

### Prerequisites
- Linux host with 20GB+ free disk space
- sudo/root access
- Tools: wget, xz-utils, losetup, parted, qemu-user-static

### Step-by-Step

#### 1. Prepare Linux Host

```bash
# Ensure you have enough space
df -h /

# Install required tools (if needed)
sudo apt-get install -y wget xz-utils util-linux parted qemu-user-static
```

#### 2. Clone Repository

```bash
git clone https://github.com/jose33bro/horaltscanner.git
cd horaltscanner
```

#### 3. Run Image Builder

```bash
# This takes 60-90 minutes!
sudo bash build_clean_os_image.sh
```

**What it does:**
- Downloads Raspberry Pi OS Bookworm 64-bit (500MB)
- Extracts base image
- Expands image (+2GB)
- Mounts filesystem
- Installs HoralScanner in chroot
- Unmounts filesystem
- Compresses image (xz)
- Creates documentation

#### 4. Output

Image will be in `horaltscanner-os-build/` directory:
```
horaltscanner-os-build/
├── horaltscanner-bookworm-lite.img.xz (compressed ~1.5GB)
├── horaltscanner-bookworm-lite.img    (uncompressed ~10GB)
└── README_IMAGE.txt                   (flashing instructions)
```

#### 5. Flash to Multiple SD Cards

```bash
# Get the compressed image
IMAGE="horaltscanner-os-build/horaltscanner-bookworm-lite.img.xz"

# Find SD card device
lsblk

# Flash (replace sdX with actual device, e.g., sdb)
sudo bash -c "xzcat $IMAGE | dd of=/dev/sdX bs=4M status=progress sync"

# Eject
sudo eject /dev/sdX
```

#### 6. Boot Pi with Image

- Insert SD card into Pi 4
- Power on
- Wait for boot (~30 seconds)
- SSH in: `ssh pi@raspberrypi.local`
- Dashboard ready at: `http://raspberrypi.local:5000`

---

## Verification & Testing

### 1. Check Service Status

```bash
sudo systemctl status horalscanner
```

Expected output:
```
● horalscanner.service - HoralScanner 3D Scanner API
     Loaded: loaded (/etc/systemd/system/horalscanner.service; enabled; vendor preset: enabled)
     Active: active (running) since ...
```

### 2. View Live Logs

```bash
sudo journalctl -u horalscanner -f
```

### 3. Test API Endpoints

```bash
# Health check
curl http://localhost:5000/api/status

# Expected response:
# {"success": true, "status": {"api": "ok", "gpio_driver": true, "stm32_driver": false, "version": "1.0.0"}}

# Get laser status
curl http://localhost:5000/api/laser/status

# Get temperature
curl http://localhost:5000/api/temperature/board
```

### 4. Access Web Dashboard

Open browser:
```
http://<your-pi-ip>:5000
```

Should show:
- ✅ **Status:** API Connected
- ✅ **GPIO Driver:** Connected
- ⚠️ **STM32 Driver:** Disconnected (until board is powered)

### 5. Test Controls

From dashboard:
- [ ] Toggle laser (if enabled)
- [ ] Change LED color
- [ ] Move motors (after wiring)
- [ ] Adjust fans
- [ ] Read temperature

---

## Troubleshooting

### Service Won't Start

```bash
# Check logs
sudo journalctl -u horalscanner -n 50

# Common issues:
# - GPIO permissions: sudo usermod -a -G gpio pi
# - Port in use: sudo lsof -i :5000
# - Python error: Check pip install output
```

### GPIO Driver Not Available

```bash
# Add user to gpio group
sudo usermod -a -G gpio pi
sudo usermod -a -G dialout pi

# Reboot
sudo reboot

# Re-check
sudo systemctl status horalscanner
```

### Can't Connect to STM32 Board

```bash
# Check USB connection
lsusb
dmesg | grep -i stm32

# Check serial ports
ls /dev/tty*

# Test connection manually
python3 -c "import serial; s=serial.Serial('/dev/ttyUSB0', 115200); print('OK')"
```

### Port 5000 Already in Use

```bash
# Find process
sudo lsof -i :5000

# Kill it
sudo kill -9 <PID>

# Or change port in horalscanner_api.py
# (not recommended)
```

### Python Import Errors

```bash
# Activate venv and reinstall
source /home/pi/horaltscanner_env/bin/activate
pip install --upgrade -r /home/pi/horaltscanner/requirements.txt
```

### Slow Performance

```bash
# Check available RAM
free -h

# Check disk space
df -h

# Check CPU temperature
vcgencmd measure_temp

# HoralScanner performance:
# - Should not use >30% CPU
# - Memory usage: ~100-200MB
# - API response <100ms
```

---

## Post-Installation Setup

### 1. Change Default Password

```bash
passwd
```

### 2. Configure Hostname

```bash
sudo raspi-config
# System Options → Hostname
```

### 3. Enable WiFi (Optional)

```bash
sudo raspi-config
# System Options → Wireless LAN
# Select country and network
```

### 4. Wire Hardware

Follow: `hardware/wiring_diagram.md`

### 5. Set Up SSH Keys (Recommended)

```bash
# On your computer
ssh-copy-id pi@raspberrypi.local

# On Pi (disable password auth)
sudo nano /etc/ssh/sshd_config
# Change: PasswordAuthentication no
sudo systemctl restart ssh
```

### 6. Enable Firewall (Recommended)

```bash
sudo apt-get install ufw
sudo ufw default deny incoming
sudo ufw default allow outgoing
sudo ufw allow 22/tcp  # SSH
sudo ufw allow 5000/tcp # HoralScanner
sudo ufw enable
```

---

## Updating HoralScanner

### Option 1: Auto-Update (Recommended)

```bash
bash /home/pi/horaltscanner/software/scripts/update.sh
```

### Option 2: Manual Update

```bash
cd /home/pi/horaltscanner
git pull origin main
source /home/pi/horaltscanner_env/bin/activate
pip install -r requirements.txt --upgrade
deactivate
sudo systemctl restart horalscanner
```

---

## Uninstalling HoralScanner

```bash
# Stop service
sudo systemctl stop horalscanner
sudo systemctl disable horalscanner

# Remove service file
sudo rm /etc/systemd/system/horalscanner.service

# Remove code (optional)
rm -rf /home/pi/horaltscanner
rm -rf /home/pi/horaltscanner_env

# Reload systemd
sudo systemctl daemon-reload
```

---

## Script Comparison

| Script | Purpose | Use When | Time |
|---|---|---|---|
| `setup_pi.sh` | Fresh install | Starting from clean Raspberry Pi OS | 30-45 min |
| `build_clean_os_image.sh` | Create reusable image | Building for multiple Pis | 60-90 min |
| `software/scripts/update.sh` | Update code only | Already running, want latest version | 5-10 min |

---

## Support

- **Issues:** https://github.com/jose33bro/horaltscanner/issues
- **Quick Start:** [QUICK_START.md](QUICK_START.md)
- **API Docs:** [USAGE.md](USAGE.md)
- **Deployment:** [DEPLOYMENT.md](DEPLOYMENT.md)

---

## Checklist

- [ ] Pi 4 with Raspberry Pi OS installed
- [ ] SSH access working
- [ ] Installation script completed
- [ ] Service running (`systemctl status horalscanner`)
- [ ] Web dashboard accessible on port 5000
- [ ] GPIO driver connected
- [ ] Hardware wired correctly
- [ ] Changed default password
- [ ] Tested at least one API endpoint
- [ ] Firewall configured (recommended)

---

**Ready to scan!** 🎉

Get started: Choose your method above and follow the steps.

EOF

cat INSTALL_GUIDE.md

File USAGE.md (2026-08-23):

# HoralScanner — Usage Guide

## Web Dashboard

Once the service is running, open your browser at:

```
http://<raspberry-pi-ip>:5000
```

### Controls

| Widget | Description |
|---|---|
| 🔴 **Lasers** | Toggle left/right laser on/off |
| 🟡 **LED RGB** | Drag R/G/B sliders or click colour presets |
| ⚙️ **Motors** | Set X/Y/Z displacement (mm) and click **Move**; use **Home All** to zero axes; **⏹ Stop** for emergency stop |
| 💨 **Fans** | Set Pi / Creality / Temp fan speed (%) and click **Apply Fans** |
| 🌡️ **Temperature** | Live board temperature from PC5 sensor |
| 📡 **Status** | API health and driver availability |

The dashboard auto-refreshes every **5 seconds**.

---

## API Reference

Base URL: `http://<host>:5000`

### Health

| Method | Path | Description |
|---|---|---|
| GET | `/api/status` | API health, driver availability, version |

**Response:**
```json
{
  "success": true,
  "status": {
    "api": "ok",
    "gpio_driver": true,
    "stm32_driver": true,
    "version": "1.0.0"
  }
}
```

### Lasers

| Method | Path | Body | Description |
|---|---|---|---|
| POST | `/api/laser/<left\|right>` | `{"state": true}` | Set laser state |
| GET | `/api/laser/status` | — | Current laser states |

### LED RGB

| Method | Path | Body | Description |
|---|---|---|---|
| POST | `/api/led/color` | `{"r":255,"g":0,"b":0}` | Set LED colour (0–255 each) |
| GET | `/api/led/status` | — | Current LED colour |

### Motors

| Method | Path | Body | Description |
|---|---|---|---|
| POST | `/api/move/<x\|y\|z>` | `{"mm": 10.0}` | Move axis by distance |
| POST | `/api/home/<x\|y\|z\|all>` | — | Home axis/all |
| POST | `/api/motor/stop` | `{"axis":"all"}` | Stop motor(s) |
| GET | `/api/motor/status` | — | Positions and movement state |

### Fans

| Method | Path | Body | Description |
|---|---|---|---|
| POST | `/api/fan/pi` | `{"percent":50}` | Pi GPIO23 fan speed |
| POST | `/api/fan/creality` | `{"speed":0.5}` | Creality PA0 fan speed |
| POST | `/api/fan/temperature` | `{"pwm":0.75}` | Temperature PA8 fan speed |
| GET | `/api/fan/status` | — | All fan speeds |

Speed accepts: `speed` (0–1), `pwm` (0–1), or `percent` (0–100).

### Temperature

| Method | Path | Description |
|---|---|---|
| GET | `/api/temperature/board` | Board temperature from PC5 (°C) |
| GET | `/api/temperature/all` | All temperature data |

---

## cURL Examples

```bash
# Health check
curl http://localhost:5000/api/status

# Turn left laser on
curl -X POST http://localhost:5000/api/laser/left \
  -H "Content-Type: application/json" \
  -d '{"state": true}'

# Set LED to red
curl -X POST http://localhost:5000/api/led/color \
  -H "Content-Type: application/json" \
  -d '{"r": 255, "g": 0, "b": 0}'

# Move X axis 10 mm
curl -X POST http://localhost:5000/api/move/x \
  -H "Content-Type: application/json" \
  -d '{"mm": 10.0}'

# Set Pi fan to 50%
curl -X POST http://localhost:5000/api/fan/pi \
  -H "Content-Type: application/json" \
  -d '{"percent": 50}'

# Read board temperature
curl http://localhost:5000/api/temperature/board
```

---

## Hardware Quick-Start

1. Connect Raspberry Pi GPIO pins as documented in `hardware/wiring_diagram.md`.
2. Plug the Creality V4.2.2 board via USB.
3. Power on and start the service: `sudo systemctl start horalscanner`.
4. Open the dashboard in a browser.
5. Use the **Status** card to confirm GPIO and STM32 drivers are available (✅).

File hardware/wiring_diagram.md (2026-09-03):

# Wiring Diagram (Concept)

- **Creality V4.2.2 (STM32F103)**
  - STEP/DIR/EN vers moteurs X (translation), Y (plateau rotatif), Z (hauteur)
  - PA0: ventilateur Creality (PWM)
  - PA8: ventilateur température carte (PWM)
  - PC5: thermistance carte (EPCOS 100K B57560G104F)
  - Endstop X: point 0 translation
  - Endstop Y: point 0 après un tour complet
  - Endstop Z: point 0 alignement Lidar TF-Luna + caméra USB Logitech
- **Raspberry Pi 4**
  - USB vers carte Creality V4.2.2 (protocole custom)
  - USB vers Lidar TF-Luna
  - USB vers caméra Logitech
  - CSI vers caméra Pi V3 NoIR
  - GPIO27/22: lasers gauche/droit, PWM 1 kHz via MOSFET
  - GPIO18/13/19: LED RGB PWM
  - GPIO23: ventilateur Pi tout-ou-rien (`1` marche, `0` arrêt)

La configuration de production utilise des sorties actives à l'état haut; le
pilote conserve aussi le comportement actif à l'état bas lorsqu'il est
configuré. Les lasers 5 V doivent être commandés par des MOSFET compatibles PWM
et démarrent à 20 % de rapport cyclique. Les autres charges doivent aussi
utiliser un étage adapté (résistance/transistor/MOSFET); aucune charge ne doit
être alimentée directement par une broche GPIO.

> GPIO18 ne doit pas être réservé par `dtoverlay=gpio-ir`, car il commande le
> canal rouge de la LED RGB.

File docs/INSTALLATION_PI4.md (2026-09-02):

# Installation Horaltscanner sur Raspberry Pi 4

Guide complet d'installation du scanner 3D USB sur un Raspberry Pi 4 avec Creality V4.2.2.

## Table des matières

1. [Prérequis matériel](#prérequis-matériel)
2. [Préparation SD Card](#préparation-sd-card)
3. [Configuration SSH](#configuration-ssh)
4. [Installation système](#installation-système)
5. [Installation Python](#installation-python)
6. [Clonage du dépôt](#clonage-du-dépôt)
7. [Configuration matériel](#configuration-matériel)
8. [Test](#test)
9. [Démarrage automatique](#démarrage-automatique)

---

## Prérequis matériel

### Composants
- **Raspberry Pi 4** (4Go RAM minimum)
- **SD Card** 32Go ou plus (Classe 10)
- **Alimentation USB-C** 5V/3A minimum
- **Câble réseau Ethernet** ou WiFi
- **Adaptateur USB** pour la Creality V4.2.2
- **Caméra Raspberry Pi V3 NoIR** (connecteur CSI)
- **Webcam USB Logitech C270**
- **LiDAR TF-Luna** (USB)
- **Dissipateur thermique** pour le Pi

### Branchements
```
Raspberry Pi 4
├── USB (moteurs STM32) → Creality V4.2.2
├── USB → Logitech C270
├── USB → LiDAR TF-Luna
├── CSI → Caméra Pi V3 NoIR
├── GPIO27 → Laser gauche
├── GPIO22 → Laser droit
├── GPIO18 → LED R (PWM)
├── GPIO13 → LED G (PWM)
├── GPIO19 → LED B (PWM)
└── GPIO23 → Ventilateur Pi
```

---

## Préparation SD Card

### 1. Télécharger Raspberry Pi OS

```bash
# Sur votre ordinateur (Linux/Mac/Windows)
# Télécharger Raspberry Pi OS Lite 64-bit depuis:
# https://www.raspberrypi.com/software/operating-systems/

# OU utiliser Raspberry Pi Imager:
# https://www.raspberrypi.com/software/
```

### 2. Flasher la SD Card

**Avec Raspberry Pi Imager (GUI):**
- Ouvrir Raspberry Pi Imager
- Sélectionner "Raspberry Pi OS (64-bit)"
- Sélectionner votre SD Card
- Cliquer "Écrire"

**Avec dd (CLI):**
```bash
# Identifier la SD Card
lsblk

# Flasher (remplacer sdX par votre device)
sudo dd if=2024-XX-XX-raspios-bookworm-arm64-lite.img of=/dev/sdX bs=4M status=progress
sync
```

### 3. Configuration initiale (avant démarrage)

Après le flashage, la SD Card contient une partition boot. Vous pouvez pré-configurer:

**Activer SSH (ajouter fichier vide):**
```bash
# Sur la partition boot:
touch /boot/ssh
```

**Pré-configurer WiFi (optionnel):**
```bash
# Créer /boot/wpa_supplicant.conf
cat > /boot/wpa_supplicant.conf << 'EOF'
ctrl_interface=DIR=/var/run/wpa_supplicant GROUP=netdev
update_config=1
country=FR

network={
    ssid="votre_wifi"
    psk="votre_mot_de_passe"
    key_mgmt=WPA-PSK
}
EOF
```

---

## Configuration SSH

### 1. Premier démarrage et connexion

```bash
# Brancher la SD Card, allumer le Pi
# Attendre ~2 minutes pour le démarrage

# Trouver l'adresse IP du Pi
arp-scan --local
# OU
nmap -sn 192.168.1.0/24
# OU (si sur réseau local)
ping raspberrypi.local

# Se connecter via SSH
ssh pi@raspberrypi.local
# OU
ssh pi@<IP_ADDRESS>

# Mot de passe par défaut: raspberry
```

### 2. Changer le mot de passe

```bash
# Sur le Pi
passwd
# Entrer le nouveau mot de passe
```

### 3. Configurer une clé SSH (recommandé)

**Sur votre ordinateur:**
```bash
# Générer une paire de clés (si vous n'en avez pas)
ssh-keygen -t ed25519 -C "horaltscanner"
# Sauvegarder dans ~/.ssh/id_horaltscanner

# Copier la clé publique vers le Pi
ssh-copy-id -i ~/.ssh/id_horaltscanner.pub pi@raspberrypi.local
# OU manuellement:
cat ~/.ssh/id_horaltscanner.pub | ssh pi@raspberrypi.local 'cat >> .ssh/authorized_keys'
```

**Vérifier la connexion sans mot de passe:**
```bash
ssh -i ~/.ssh/id_horaltscanner pi@raspberrypi.local
```

**Configurer ~/.ssh/config (optionnel):**
```bash
cat >> ~/.ssh/config << 'EOF'
Host horaltscanner
    HostName raspberrypi.local
    User pi
    IdentityFile ~/.ssh/id_horaltscanner
    StrictHostKeyChecking no
EOF

# Maintenant vous pouvez faire:
ssh horaltscanner
```

### 4. Désactiver l'authentification par mot de passe (sécurité)

```bash
# Sur le Pi
sudo nano /etc/ssh/sshd_config
# Modifier/ajouter ces lignes:
# PasswordAuthentication no
# PubkeyAuthentication yes

sudo systemctl restart ssh
```

---

## Installation système

```bash
# Sur le Pi, via SSH
ssh pi@raspberrypi.local

# Mettre à jour le système
sudo apt update
sudo apt upgrade -y

# Installer les dépendances système
sudo apt install -y \
    python3-pip \
    python3-dev \
    git \
    cmake \
    build-essential \
    libopencv-dev \
    python3-opencv \
    libatlas-base-dev \
    libjasper-dev \
    libtiff5 \
    libjasper1 \
    libharfbuzz0b \
    libwebp6 \
    libtiff5 \
    libopenjp2-7 \
    libopenjp2-7-dev \
    libharfbuzz0b \
    libwebp6 \
    libjasper1 \
    libtiff5 \
    libatlas-base-dev \
    libharfbuzz0b \
    libwebp6 \
    libopenjp2-7

# Activer les interfaces I2C, SPI, Camera (optionnel)
sudo raspi-config
# Interface Options → Camera → Enable
# Interface Options → I2C → Enable
# Interface Options → Serial → Enable (pour LiDAR)
```

---

## Installation Python

```bash
# Créer un virtualenv
cd ~
python3 -m venv horaltscanner_env
source horaltscanner_env/bin/activate

# Mettre à pip à jour
pip install --upgrade pip setuptools wheel

# Installer les dépendances Python
pip install pyserial>=3.5
pip install gpiozero>=1.6.0
pip install opencv-python>=4.5
pip install numpy>=1.21.0
pip install pillow>=8.3.0
pip install pytest>=7.0.0
pip install pytest-cov>=3.0.0

# Optionnel: picamera2 (caméra Pi)
pip install picamera2
```

---

## Clonage du dépôt

```bash
# Se placer dans le répertoire
cd ~

# Configurer Git (si nécessaire)
git config --global user.name "Votre Nom"
git config --global user.email "votre.email@example.com"

# Cloner le dépôt
git clone https://github.com/jose33bro/horaltscanner.git
cd horaltscanner

# Sélectionner la branche USB
git checkout copilot/create-usb-firmware

# Vérifier les fichiers
ls -la firmware/raspberry_pi/
ls -la software/tests/
```

---

## Configuration matériel

### 1. Identifier les ports USB

```bash
# Lister tous les périphériques USB
lsusb

# Lister les ports série
ls -la /dev/ttyUSB*
ls -la /dev/ttyACM*

# Obtenir les identifiants persistants
ls -la /dev/serial/by-id/

# Exemple:
# /dev/serial/by-id/usb-1a86_USB_Serial-if00-port0  → Creality (moteurs)
# /dev/ttyUSB1                                       → LiDAR TF-Luna
```

### 2. Mettre à jour config.py

```bash
# Éditer la configuration
nano ~/horaltscanner/firmware/raspberry_pi/config.py

# Vérifier/modifier:
# USB_PORT = "/dev/serial/by-id/usb-1a86_USB_Serial-if00-port0"
# GPIO pins (27, 22, 18, 13, 19, 23)
```

### 3. Tester les connexions

```bash
# Vérifier USB moteurs
python3 << 'EOF'
import sys
sys.path.insert(0, '/home/pi/horaltscanner/firmware')
from raspberry_pi.usb_driver import USBDriver

driver = USBDriver()
if driver.connect():
    print("✓ Moteurs connectés")
    driver.ping()
    driver.disconnect()
else:
    print("✗ Erreur connexion moteurs")
EOF

# Vérifier GPIO
python3 << 'EOF'
import sys
sys.path.insert(0, '/home/pi/horaltscanner/firmware')
from raspberry_pi.gpio_laser_control import GPIOLaserControl

gpio = GPIOLaserControl(use_board=False)  # Mode simulation
print("✓ GPIO initialisé (simulation)")
EOF

# Vérifier caméras
v4l2-ctl --list-devices
```

---

## Test

### 1. Tests unitaires

```bash
# Activer virtualenv
source ~/horaltscanner_env/bin/activate
cd ~/horaltscanner

# Exécuter tous les tests
python -m pytest software/tests/ -v

# Tests spécifiques
python -m pytest software/tests/test_usb_driver.py -v
python -m pytest software/tests/test_motor_control.py -v
```

### 2. Test d'initialisation scanner

```bash
# Mode simulation (sans matériel)
python3 << 'EOF'
import sys
sys.path.insert(0, '/home/pi/horaltscanner/firmware')
from raspberry_pi.scanner_app import ScannerApp

app = ScannerApp(use_gpio=False)  # Simulation
if app.initialize():
    print("✓ Scanner initialisé")
    app.laser_test(100)
    app.led_test()
    app.shutdown()
else:
    print("✗ Erreur initialisation")
EOF
```

### 3. Test complet avec matériel

```bash
# Vérifier que tout est connecté!
python3 << 'EOF'
import sys
sys.path.insert(0, '/home/pi/horaltscanner/firmware')
from raspberry_pi.scanner_app_full import ScannerAppFull

with ScannerAppFull(use_gpio=True) as scanner:
    print(f"Moteurs hômés: {scanner.motors.is_homed()}")
    print(f"Caméras: {scanner.cameras is not None}")
    print(f"LiDAR: {scanner.lidar is not None}")
EOF
```

---

## Démarrage automatique

### 1. Créer un script systemd

```bash
# Créer le service
sudo nano /etc/systemd/system/horaltscanner.service
```

```ini
[Unit]
Description=Horaltscanner 3D Scanner
After=network.target

[Service]
Type=simple
User=pi
WorkingDirectory=/home/pi/horaltscanner
Environment="PATH=/home/pi/horaltscanner_env/bin"
ExecStart=/home/pi/horaltscanner_env/bin/python3 -m firmware.raspberry_pi.scanner_app_full
Restart=always
RestartSec=10

[Install]
WantedBy=multi-user.target
EOF
```

### 2. Activer le service

```bash
# Recharger les services
sudo systemctl daemon-reload

# Activer au démarrage
sudo systemctl enable horaltscanner.service

# Démarrer le service
sudo systemctl start horaltscanner.service

# Vérifier le statut
sudo systemctl status horaltscanner.service

# Voir les logs
journalctl -u horaltscanner.service -f
```

---

## Dépannage

### Problème: Impossible de se connecter en SSH

```bash
# Vérifier que SSH est activé
sudo systemctl status ssh

# Vérifier l'adresse IP
ip addr show eth0
# OU
ifconfig

# Trouver le Pi sur le réseau
arp-scan --local | grep -i raspberry
```

### Problème: Import module échoue

```bash
# Vérifier le PYTHONPATH
export PYTHONPATH=/home/pi/horaltscanner/firmware:$PYTHONPATH
python3 -c "from raspberry_pi import USBDriver"
```

### Problème: Ports USB ne sont pas trouvés

```bash
# Vérifier les permissions
sudo usermod -a -G dialout pi
sudo usermod -a -G gpio pi

# Redémarrer
sudo reboot

# Vérifier après redémarrage
ls -la /dev/ttyUSB*
ls -la /dev/serial/by-id/
```

### Problème: GPIO ne fonctionne pas

```bash
# Vérifier que l'utilisateur est dans le groupe gpio
groups pi

# Si absent, ajouter:
sudo usermod -a -G gpio pi

# Redémarrer
sudo reboot
```

---

## Accès au dépôt depuis le Pi

### Avec SSH key

```bash
# Sur le Pi, générer une clé
ssh-keygen -t ed25519 -C "pi@horaltscanner"

# Afficher la clé publique
cat ~/.ssh/id_ed25519.pub

# Ajouter cette clé dans GitHub:
# Settings → SSH and GPG keys → New SSH key

# Tester la connexion
ssh -T git@github.com

# Cloner avec SSH
git clone git@github.com:jose33bro/horaltscanner.git
```

---

## Utilisation

### Exemple simple

```bash
# Activer virtualenv
source ~/horaltscanner_env/bin/activate

# Créer un script de scan
cat > ~/scan.py << 'EOF'
import sys
sys.path.insert(0, '/home/pi/horaltscanner/firmware')
from raspberry_pi.scanner_app_full import ScannerAppFull

with ScannerAppFull() as scanner:
    # Scan simple
    scanner.run_full_scan(
        num_positions=10,
        z_heights=[50, 100],
        lidar_samples=20
    )
EOF

# Exécuter
python3 ~/scan.py
```

### Outputs

Les résultats du scan sont sauvegardés dans:
```
/tmp/horaltscanner_scan_YYYYMMDD_HHMMSS/
├── images/
│   ├── pi_v3/
│   │   ├── position_00000_pi.png
│   │   └── ...
│   └── usb_logitech/
│       ├── position_00000_usb.png
│       └── ...
├── lidar_measurements.csv
└── scan_metadata.json
```

---

## Support

Pour l'aide:
- Consulter les logs: `journalctl -u horaltscanner.service -f`
- Vérifier les tests: `python -m pytest software/tests/ -v`
- GitHub Issues: https://github.com/jose33bro/horaltscanner/issues

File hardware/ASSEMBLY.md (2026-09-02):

# HoralScanner — Assembly Guide

## Overview
Step-by-step instructions for assembling the HoralScanner mechanical and electrical systems. Estimated time: **4–6 hours** for first build.

---

## Pre-Assembly Checklist

- [ ] All parts from [BOM.md](BOM.md) sourced and verified
- [ ] Raspberry Pi OS (Bookworm) flashed to SD card
- [ ] Soldering iron & solder ready (for GPIO connections)
- [ ] 3D-printed PLA parts cleaned (no support material stuck)
- [ ] Work surface clean and well-lit
- [ ] Multimeter available for continuity checks

---

## Phase 1: Motion Platform Base (Creality Hyper)

### Step 1.1: Assemble Frame
1. Mount the **Creality V4.2.2 board** on the **motion platform base** using M3 screws
   - Ensure power connector faces accessible direction (rear or side)
   - Verify no components interfere with motor mounts

2. Mount **NEMA 17 stepper motors** to the motor mounts:
   - **X-axis motor** → Left side, horizontal orientation
   - **Y-axis motor** → Center, horizontal orientation  
   - **Z-axis motor** → Right side, vertical orientation
   - Use M3 machine screws (4 per motor)

### Step 1.2: Install Ball Screw Assemblies
For each axis (X, Y, Z):
1. Thread **M5 × 40 ball screw** into the stepper motor coupler
2. Secure with M5 lock nut (0.8 pitch)
3. Ensure **ball Ø6.5 mm** sits freely in the ball nut (no binding)
4. Mount bearing blocks at each end:
   - **Rear bearing** (fixed) — M5 tapped hole in base plate
   - **Front bearing** (floating) — Adjustable M5 hole for preload

### Step 1.3: Configure Motion Axes

**X-Axis (Rotating Platform):**
- Ball screw orientation: **Horizontal, left-to-right**
- Coupling: motor shaft → ball screw (flexible coupler preferred)
- Platform attachment: bearing block → rotating table clamp

**Y-Axis (Linear Translation):**
- Ball screw orientation: **Horizontal, rear-to-front**
- Travel range: 0–100 mm (adjust for your build)
- Endstop: Mount **microswitch** at Y=0 (rear limit)
- Cable routing: Route USB (TF-Luna) along Y-carriage with drag chain

**Z-Axis (Height Adjustment):**
- Ball screw orientation: **Vertical, bottom-to-top**
- Travel range: 0–50 mm (camera height clearance)
- Soft limits: motor_control will enforce in firmware
- **Vertical Offset Calibration:** Set Z=0 reference **+5 mm above lowest position**
  - This allows TF-Luna (mounted on Y-carriage) to measure at optimal distance

---

## Phase 2: Camera Support Assembly

### Step 2.1: Prepare PLA Parts
1. Inspect **Camera Support Plate** (28.05 × 7 × 1 mm):
   - Verify **socket Ø6.9 mm** is centered (measure with caliper)
   - Check **4 mm petal retainers** for any print defects
   - Drill/ream M3 clearance holes if needed (target Ø3.2 mm)

2. Inspect **Base Plate**:
   - Verify **M5 tapped hole** is clean (test-thread a screw; back out cleanly)
   - Check **orientation marking** (rear → front label visible)
   - Measure **+5 mm vertical offset** from origin

### Step 2.2: Mount Camera Support Plate
1. Position **Camera Support Plate** on Z-carriage (top of Z-axis):
   - Align **socket Ø6.9** with Logitech USB camera lens
   - Ensure **rear → front orientation** matches Y-carriage direction
   - Leave **1 mm clearance** from ball screw

2. Fasten with **M3 screws** through both clearance holes:
   - Recommended: M3×10 pan-head (nylon or stainless)
   - Torque: 1.5–2 N·m (avoid stripping PLA)
   - Verify plate is level (use small spirit level)

3. Insert **Logitech USB camera** into socket:
   - Push gently until lens contacts socket walls
   - **4 mm petal retainers** should grip connector housing
   - Do NOT force (risk breaking petals)
   - Verify camera is horizontal and points downward at ~45°

### Step 2.3: Secure Cables
1. Route **USB camera cable** along Y-carriage using cable ties
2. Route to rear of frame; connect to **Raspberry Pi USB 2.0 port**
3. Leave **100 mm slack** for Y-axis motion (to avoid binding)

---

## Phase 3: Sensor Integration

### Step 3.1: TF-Luna LiDAR Mounting
1. Mount **TF-Luna on Y-carriage** (same as camera, parallel orientation):
   - Optical axis points **downward (Z-negative)**
   - Position **50 mm ahead of camera** (toward front of frame)
   - Use mounting bracket or 3D-printed holder (Ø16 mm typical)

2. Connect USB to **Raspberry Pi USB 2.0 port** (or via USB hub)
3. Verify LiDAR has clear view of object below (no obstructions)

### Step 3.2: Endstop Sensor (Y-Axis)
1. Mount **microswitch (NO)** at Y=0 (rear limit):
   - Position so Y-carriage contacts lever at soft limit
   - Solder connections: common → GND, NO → Creality endstop pin

2. Electrically connect to **Creality V4.2.2 endstop header** (pull-up enabled in firmware)

### Step 3.3: Thermistor (Board Temp)
- Already integrated in Creality V4.2.2 (PC5 ADC)
- No assembly required; verify firmware reads correctly in dashboard

---

## Phase 4: GPIO Wiring (Raspberry Pi)

### Step 4.1: Laser Outputs
1. **Laser Left (GPIO 27)**:
   - Connect laser +5V input to Pi 5V rail (via 330Ω resistor)
   - Connect laser GND to Pi GND
   - Connect laser trigger (if available) to GPIO 27 (digital output, 3.3V)
   - **Safety:** Test with multimeter before powering laser

2. **Laser Right (GPIO 22)**:
   - Follow same pattern as Left laser
   - Verify both lasers fire when dashboard toggles them

### Step 4.2: LED RGB Control
1. **LED Red (GPIO 18 PWM)**:
   - Connect LED anode to +5V rail
   - Connect LED cathode to GPIO 18 via 330Ω resistor + 2N2222 transistor
   - Transistor base → GPIO 18 (3.3V → 5V level conversion)

2. **LED Green (GPIO 13 PWM)** and **LED Blue (GPIO 19 PWM)**:
   - Repeat same pattern for each color
   - Verify all three colors blend properly on dashboard

### Step 4.3: Cooling Fan (GPIO 23)
1. Connect **5V fan** to Pi GPIO 23 with transistor driver:
   - Fan +5V → +5V rail
   - Fan GND → Transistor collector → GPIO 23
   - Fan will auto-start at 55°C, stop at 45°C

2. Test: Run `watch vcgencmd measure_temp` and confirm fan spins above threshold

### Step 4.4: Cable Management
- Use **Dupont jumper wires (F-F)** for all GPIO connections
- Label each wire with masking tape (e.g., "GPIO27_LaserLeft")
- Route cables away from motor wiring (avoid EMI)
- Secure with cable ties; leave 50 mm slack at connector ends

---

## Phase 5: Power & Communication

### Step 5.1: USB Connections (Raspberry Pi)
1. **Creality V4.2.2** → Pi USB 2.0 Port (Micro-USB):
   - Use **high-quality data-capable cable** (not power-only)
   - Verify connection: `lsusb` should show STM32 device
   - Check: `ls -l /dev/ttyUSB*` (should see `/dev/ttyUSB0` or similar)

2. **TF-Luna LiDAR** → Pi USB 2.0 Port:
   - Route USB parallel to camera cable
   - Verify: `cat /dev/ttyUSB1` shows distance readings (numbers, not gibberish)

3. **Logitech USB Camera** → Pi USB 2.0 Port:
   - Already connected in Phase 2.3
   - Verify: `ls /dev/video*` shows `/dev/video0`

### Step 5.2: Power Supply
1. Connect **24V PSU** to:
   - Creality V4.2.2 power jack (2.1mm barrel or XT60)
   - Raspberry Pi via USB-C power supply (separate 5V, 3A minimum)
   
2. Test polarity with **multimeter** before connecting boards

3. Power sequence:
   - Turn ON Creality 24V first
   - Then turn ON Pi 5V
   - (Reverse order when shutting down)

### Step 5.3: CSI Camera (Pi Camera V3, Optional)
1. Open **CSI ribbon connector** on Raspberry Pi (pull blue tab gently)
2. Insert **22-pin ribbon cable** until it clicks
3. Camera module should be mounted **above the X-axis platform** with 45° downward tilt

---

## Phase 6: Software & Firmware Setup

### Step 6.1: Flash Raspberry Pi OS
```bash
# On your workstation:
# 1. Download Raspberry Pi Imager
# 2. Select "Raspberry Pi OS (64-bit, Bookworm)"
# 3. Flash to SD card
# 4. Boot Pi and open terminal
```

### Step 6.2: Install HoralScanner
```bash
ssh pi@raspberrypi.local
sudo bash -c "curl -sSL https://raw.githubusercontent.com/jose33bro/horaltscanner/main/setup_pi.sh | bash"
sudo reboot
```

### Step 6.3: Configure Serial Devices (Creality & TF-Luna)
```bash
# Identify which USB device is which:
lsusb
ls -l /dev/ttyUSB*

# Optionally, create stable aliases:
bash /home/pi/horaltscanner/software/scripts/configure_serial_devices.sh
```

### Step 6.4: Verify GPIO & Drivers
```bash
sudo systemctl status horalscanner
sudo journalctl -u horalscanner -n 50

# Test API:
curl http://localhost:5000/api/status
curl -X POST http://localhost:5000/api/laser/left -H "Content-Type: application/json" -d '{"state": true}'
```

---

## Phase 7: Calibration & Testing

### Step 7.1: Motor Homing
1. Open dashboard: `http://<pi-ip>:5000`
2. Click **"Home All"** button
   - Motors should move to endstops (should hear mechanical clicks/stops)
   - Positions should reset to (0, 0, 0)
3. Check `journalctl` for errors; if homing fails, verify endstop wiring

### Step 7.2: Camera Focus & Alignment
1. Navigate to **Cameras** section in dashboard
2. Click **"Test USB Camera"** or **"Test Pi Camera"**
3. Verify image appears and is in focus
4. Adjust camera height (Z-axis) until object below is sharp

### Step 7.3: LiDAR Calibration
1. Place **known reference object** (e.g., flat board) 300 mm below LiDAR
2. Navigate to **LiDAR** section in dashboard
3. Click **"Calibrate"** with distance = 300 mm
4. Verify offset is stored; re-read distance should match reference

### Step 7.4: Laser Alignment (Optional)
1. Power ON both lasers from dashboard
2. Visually verify red dots appear on object below
3. Both lasers should form a **triangle with camera for triangulation**

### Step 7.5: Test Scan
1. Place small object (e.g., cube) on rotating platform below camera/laser
2. Navigate to **Scan** section in dashboard
3. Click **"Start Scan"** (full rotation, ~1 minute)
4. Monitor `journalctl` for errors
5. Once complete, click **"Reconstruct Model"**
6. Download STL and inspect in MeshLab or Cura

---

## Phase 8: Final Assembly & Enclosure (Optional)

### Step 8.1: Cable Routing
1. Bundle all **power cables** together (separate from signal cables)
2. Route behind frame or in cable tray
3. Label all connectors with masking tape

### Step 8.2: Dust Cover (Optional)
1. 3D-print or fabricate **acrylic enclosure** around scanner
2. Ensure adequate **airflow** for cooling fan
3. Add **access panel** for USB connections and power

### Step 8.3: Documentation
1. Take **photos of your build** (top, side, detail views)
2. Record any **deviations from this guide** (custom parts, modifications)
3. Create **assembly log** with dates and part serial numbers

---

## Troubleshooting

| Issue | Cause | Solution |
|---|---|---|
| Motors don't move after homing | Unhomed axis | Run "Home All" first; check endstop wiring |
| Camera image is blurry | Focus issue | Adjust Z-axis height; verify USB camera is secured |
| LiDAR reads 0 mm | Connection issue | Check USB port; verify `/dev/ttyUSB*` exists; run `cat /dev/ttyUSBn` |
| Laser won't turn ON | GPIO wiring issue | Verify GPIO27/22 with `gpio readall`; check transistor |
| Service fails to start | Missing drivers | Run `sudo systemctl status horalscanner` and check logs |
| Creality board won't connect | Serial port issue | Check USB cable quality; verify baud rate in config |

---

## Safety Warnings

⚠️ **Laser Safety:**
- Do NOT look directly into laser beam
- Wear appropriate laser safety glasses when powering lasers
- Keep hand/objects away from rotating platform during scans

⚠️ **Electrical Safety:**
- 24V power can cause injury; insulate all exposed connections
- Verify polarity before powering Creality board
- Shut down Pi gracefully (`sudo shutdown -h now`) before disconnecting power

⚠️ **Moving Parts:**
- Keep hair/loose clothing away from motors and ball screws
- Test movement with hand near limit before full motion
- Always verify endstops are installed before homing

---

## Version History

| Date | Version | Changes |
|---|---|---|
| 2026-08-29 | 1.0.0 | Initial assembly guide with Creality Hyper, PLA parts, GPIO wiring, calibration steps |

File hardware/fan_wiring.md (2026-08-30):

# Câblage ventilateur 24V - Horaltscanner

## Ventilateur du Raspberry Pi (GPIO23)

Le ventilateur de refroidissement du Raspberry Pi est distinct du ventilateur
24V de la carte Creality. Le service HoralScanner le commande en tout-ou-rien
sur **GPIO23** (broche physique 16): `1` l'active et `0` le désactive.

Le service lit `/sys/class/thermal/thermal_zone0/temp` toutes les 5 secondes:

- démarrage du ventilateur à 55°C;
- arrêt à 45°C;
- maintien de l'état entre 45°C et 55°C pour éviter les commutations rapides;
- activation de sécurité si la température CPU ne peut pas être lue.

```text
GPIO23 ──[1 kΩ]── Gate MOSFET logique
GND Pi ────────── Source MOSFET
Drain MOSFET ──── Ventilateur -
5V Pi ─────────── Ventilateur +
```

Ne jamais alimenter le ventilateur directement depuis GPIO23. Utiliser un
MOSFET logique et une diode de roue libre, avec une masse commune.

Test via l'API:

```bash
curl -X POST http://localhost:5000/api/fan/pi \
  -H 'Content-Type: application/json' \
  -d '{"percent":100}'
```

## Vue d'ensemble

Le ventilateur de refroidissement de la carte Creality V4.2.2 est alimenté en **24V DC**
et contrôlé par la broche **PC6 (PWM)** via un transistor ou relay.

## Spécifications du ventilateur

| Paramètre | Valeur |
|---|---|
| Tension d'alimentation | 24V DC |
| Courant typique | 0.3A - 0.5A |
| Méthode de contrôle | PWM via relay ou MOSFET |
| Température de démarrage | 50°C (configurable dans `temperature_fan.cfg`) |
| Taille recommandée | 40x40mm ou 60x60mm |

---

## Schéma de câblage complet

### Avec transistor NPN (méthode recommandée)

```
Creality V4.2.2:
                     24V DC
                      │
                   [Fusible 2A]
                      │
                   ┌──┴──────────┐
                   │           [Diode 1N4007]
               [Ventilateur]   (cathode→+24V)
                   │           │
                   └──────┬────┘
                          │
                   [Collecteur NPN]
                          │
              PC6 ─[470Ω]─[Base NPN (2N2222)]
                          │
                   [Émetteur]
                          │
                         GND

Composants:
- Transistor NPN: 2N2222, BC547, ou TIP120 (pour ventilateurs > 500mA)
- Résistance base: 470Ω (ou 1K pour sécurité)
- Diode de roue libre: 1N4007 (OBLIGATOIRE - protège le transistor)
- Fusible: 2A rapide (protection alimentation)
```

### Avec relay 5V (méthode alternative)

```
Raspberry Pi 5V ──► Module relay 5V ──► Alimentation 24V ventilateur
PC6 ──► Signal de contrôle relay
GND ──► GND commun
```

---

## Connexion sur la carte Creality V4.2.2

Sur la Creality V4.2.2, le connecteur ventilateur principal est:

| Pin | Signal |
|-----|---|
| + | 24V DC (contrôlé PWM PC6) |
| - | GND |

Le connecteur est marqué **"FAN"** sur la carte.

> **Note**: La broche PC6 génère un signal PWM. Le transistor ou relay
> convertit ce signal basse tension en commutation 24V pour le ventilateur.

---

## Configuration logicielle

La configuration du ventilateur est gérée par l'API HoralScanner via `software/api/horalscanner_api.py`.

Pour modifier la température de déclenchement, éditer `config/horalscanner_config.json`.

---

## Test du ventilateur

Via l'API REST:

```bash
# Activer le ventilateur Pi à 50%
curl -X POST http://localhost:5000/api/fan/pi -H "Content-Type: application/json" -d '{"percent": 50}'

# Vérifier les températures
curl http://localhost:5000/api/temperature/all

# Désactiver le ventilateur
curl -X POST http://localhost:5000/api/fan/pi -H "Content-Type: application/json" -d '{"percent": 0}'
```

---

## Notes de sécurité

- **Toujours installer la diode de roue libre** - sans elle, le transistor peut
  être détruit par les surtensions de la bobine du ventilateur
- Vérifier la polarité du ventilateur avant connexion
- Utiliser un câble de section min 0.5mm² pour 24V

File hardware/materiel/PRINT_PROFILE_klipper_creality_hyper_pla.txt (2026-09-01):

[PROFIL GLOBAL - KLIPPER + CREALITY HYPER PLA - BUSE 0.4]

Température buse: 215°C
Température plateau: 60°C
Hauteur de couche: 0.16 mm
Hauteur 1ère couche: 0.20 mm
Largeur de ligne: 0.42 mm
Parois (walls/perimeters): 6
Top layers: 7
Bottom layers: 7
Infill: 35% (Gyroid ou Cubic)
Ventilation: 100% à partir de la couche 3
Vitesse paroi externe: 22 mm/s
Vitesse paroi interne: 35 mm/s
Vitesse infill: 50 mm/s
Vitesse déplacement: 160 mm/s
Vitesse 1ère couche: 15 mm/s
Brim: 8 mm (tige), 6 mm (base), 3-5 mm (roue)
Compensation XY: -0.04 mm
Compensation XY 1ère couche: -0.12 mm
Seam: arrière
Coasting: OFF
Outer before inner walls: ON
Elephant foot compensation: 0.20 mm (PrusaSlicer)

[REGLAGE SUPPORT - BASE PI_CAMERA_TILT_BASE.STL]
Support: OUI
Type: Everywhere
Overhang angle: 55°
Support density: 12%
Support interface: ON
Interface layers: 2
Z distance support: 0.22 mm
X/Y distance support: 0.6 mm

[ORIENTATION DES PIECES]
1) pi_camera_tilt_base.stl
   - Mettre le grand dos de la plaque contre le plateau (à plat)
   - Support OUI (réglages ci-dessus)

2) ball_screw_M5x40_ball5_square_flat.stl
   - Déjà orientée à plat
   - Support NON (ou touching buildplate only si besoin)
   - Brim 8 mm

3) knurled_wheel_D100_T15_pitch5_flattooth.stl
   - Grande face à plat
   - Support NON
   - Brim 3-5 mm (optionnel)

[AJUSTEMENT FILETAGE M5/M3 APRES TEST]
Si c'est trop serré:
  - XY compensation = -0.06 mm
  - ou monter buse à 218°C
Si c'est trop lâche:
  - XY compensation = -0.02 mm ou 0.00 mm

[START GCODE KLIPPER]
M140 S{material_bed_temperature_layer_0}
M190 S{material_bed_temperature_layer_0}
M104 S{material_print_temperature_layer_0}
M109 S{material_print_temperature_layer_0}
G28
BED_MESH_PROFILE LOAD=default
G92 E0
G1 Z2.0 F3000

[END GCODE KLIPPER]
G92 E0
G1 E-2 F1800
G1 Z10 F3000
G1 X0 Y220 F6000
M104 S0
M140 S0
M107

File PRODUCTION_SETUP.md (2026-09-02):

# 🚀 Horaltscanner - Production Setup Guide (Raspberry Pi 4)

Guide complet pour déployer Horaltscanner en production sur Raspberry Pi 4 avec Gunicorn + systemd.

---

## 📋 Prerequisites

- Raspberry Pi 4 (4GB RAM minimum recommandé)
- Raspberry Pi OS Bookworm (64-bit recommandé)
- SSH accès à votre RPi
- `git` installé sur le RPi
- `python3-full` installé (`sudo apt install python3-full`)

---

## ✅ Step 1: Clone le repository

```bash
cd ~
git clone https://github.com/jose33bro/horaltscanner.git
cd horaltscanner
```

---

## ✅ Step 2: Crée un virtual environment

```bash
# Crée le venv
python3 -m venv ~/horaltscanner_env

# Active le venv
source ~/horaltscanner_env/bin/activate

# Upgrade pip
pip install --upgrade pip setuptools wheel
```

---

## ✅ Step 3: Installe les dépendances

```bash
# Depuis le repo directory (avec venv activé)
pip install -r requirements.txt
```

### ⚠️ Open3D sur ARM64

Si vous êtes sur **Raspberry Pi OS 64-bit**, Open3D n'a pas de wheels PyPI. Compilez-le:

```bash
bash software/scripts/install_open3d_pi.sh
```

(Cela prend ~30-60 minutes. Le script compile avec seulement 2 jobs pour économiser la mémoire)

---

## ✅ Step 4: Teste manuellement (optionnel)

Avant de déployer via systemd, testez que tout fonctionne:

```bash
# Depuis le repo root
cd software
gunicorn \
  --workers 1 \
  --worker-class gevent \
  --bind 127.0.0.1:5000 \
  api:create_app

# Dans une autre fenêtre SSH:
curl http://localhost:5000/api/health
# Devrait répondre: {"status": "ok"}
```

Ctrl+C pour arrêter.

---

## ✅ Step 5: Crée le service systemd

Crée le fichier `/etc/systemd/system/horaltscanner.service`:

```bash
sudo tee /etc/systemd/system/horaltscanner.service > /dev/null <<'EOF'
[Unit]
Description=HoralScanner 3D Scanner API (Gunicorn + Gevent)
After=network.target
Wants=network-online.target

[Service]
Type=notify
User=pi
WorkingDirectory=/home/pi/horaltscanner
Environment="PATH=/home/pi/horaltscanner_env/bin"
Environment="PYTHONUNBUFFERED=1"

# Un seul processus doit posseder le GPIO, les ports serie et les cameras.
ExecStart=/home/pi/horaltscanner_env/bin/gunicorn \
  --workers 1 \
  --worker-class gevent \
  --bind 0.0.0.0:5000 \
  --access-logfile - \
  --error-logfile - \
  software.api:create_app

# Redémarrer automatiquement en cas de crash
Restart=always
RestartSec=10

# Logs
StandardOutput=journal
StandardError=journal
SyslogIdentifier=horaltscanner

# Sécurité
NoNewPrivileges=true

[Install]
WantedBy=multi-user.target
EOF
```

---

## ✅ Step 6: Active et démarre le service

```bash
# Recharge systemd
sudo systemctl daemon-reload

# Active au démarrage
sudo systemctl enable horaltscanner

# Démarre le service
sudo systemctl start horaltscanner

# Vérifie le statut
sudo systemctl status horaltscanner

# Vois les logs (dernières 50 lignes)
sudo journalctl -u horaltscanner -n 50 -f
```

---

## ✅ Step 7: Vérifie que ça marche

```bash
# Depuis votre machine locale (remplacez <pi-ip> par l'IP de votre RPi):
curl http://<pi-ip>:5000/api/health
# Devrait répondre: {"status": "ok"}

# Teste un scan simple via le dashboard:
# Ouvrez http://<pi-ip>:5000 dans un navigateur
```

---

## 📊 Monitoring

### Voir les logs en temps réel
```bash
sudo journalctl -u horaltscanner -f
```

### Redémarrer le service
```bash
sudo systemctl restart horaltscanner
```

### Arrêter le service
```bash
sudo systemctl stop horaltscanner
```

### Voir le statut
```bash
sudo systemctl status horaltscanner
```

---

## 🐛 Troubleshooting

### Port 5000 déjà utilisé
```bash
# Trouve quel processus l'utilise:
sudo lsof -i :5000

# Tue-le:
sudo kill -9 <PID>
```

### Import error: `ModuleNotFoundError: No module named 'gevent'`
```bash
# Réactive le venv et réinstalle les dépendances:
source ~/horaltscanner_env/bin/activate
pip install -r requirements.txt
sudo systemctl restart horaltscanner
```

### Reconstruction très lente / API freezes
- Vérifiez que vous utilisez **Gunicorn** (pas `python api/horalscanner_api.py`)
- Vérifiez que vous avez **1 worker** configuré; le matériel et l'état du scan ont un propriétaire unique
- Vérifiez que vous utilisez **gevent** worker class (non-bloquant)

### Open3D import error
```bash
# Vérifiez que Open3D est installé:
source ~/horaltscanner_env/bin/activate
python3 -c "import open3d; print(open3d.__version__)"

# Si erreur, compilez-le:
bash software/scripts/install_open3d_pi.sh
```

---

## 📈 Performance Tips

1. **1 worker** pour tout déploiement matériel:
   - Ne l'augmentez pas: GPIO, série, caméras et état du scan sont partagés
   - Utilisez gevent et les tâches d'arrière-plan pour conserver une API réactive

2. **Gevent worker class** élimine le blocage I/O:
   - Les captures d'image, uploads, et reads API deviennent async
   - Le Poisson reconstruction tourne en background thread

3. **Asynchronous reconstruction** (PR #83):
   - `POST /api/model/reconstruct` retourne immédiatement
   - Poll `GET /api/model/status` pour voir la progression
   - N'utilise plus de temp files (bytesIO in-memory)

4. **Bounded point cloud** (PR #82):
   - Max 200k points (~500MB)
   - Les anciens points sont auto-droppés (FIFO)
   - Pas de crash OOM sur long scans

---

## 🔄 Mise à Jour

Pour mettre à jour le code:

```bash
cd ~/horaltscanner
git pull origin main
source ~/horaltscanner_env/bin/activate
pip install -r requirements.txt
sudo systemctl restart horaltscanner
```

---

## 📝 Logs et Debugging

### Logs du service
```bash
sudo journalctl -u horaltscanner -n 100 --no-pager
```

### Logs en temps réel
```bash
sudo journalctl -u horaltscanner -f
```

### Logs depuis une date
```bash
sudo journalctl -u horaltscanner --since "2026-09-02 14:00:00"
```

---

## 🎯 Vérification Finale

Une fois déployé, vérifiez:

- [ ] Service démarre au boot: `sudo systemctl is-enabled horaltscanner` → `enabled`
- [ ] Service tourne: `sudo systemctl is-active horaltscanner` → `active`
- [ ] API répond: `curl http://localhost:5000/api/health` → `{"status": "ok"}`
- [ ] Dashboard accessible: `http://<pi-ip>:5000` dans un navigateur
- [ ] Reconstruction non-bloquante: lancez un scan, puis poll `/api/model/status`

---

## 💡 Notes

- **Flask dev server** (`python api/horalscanner_api.py`) est **JAMAIS** production-ready car:
  - Single-threaded → blocage si reconstruction, capture, ou UI requête concurrente
  - Pas de gestion gracieuse des erreurs
  - Pas de logging structuré
  - Pas de gestion des signaux (SIGTERM, etc.)

- **Gunicorn + gevent** résout tout cela:
  - Multi-worker concurrence
  - Gevent rend I/O et threads non-bloquants
  - Graceful shutdown + restart
  - Logging structuré via systemd journal

---

**Horaltscanner est maintenant en production sur votre RPi4! 🚀**

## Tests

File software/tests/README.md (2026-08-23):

# Horaltscanner Tests

Tests unitaires et d'intégration pour le scanner 3D USB.

## Structure

```
software/tests/
├── conftest.py              # Fixtures pytest communes
├── test_usb_driver.py       # Tests driver USB
├── test_motor_control.py    # Tests contrôleur moteurs
├── test_gpio_control.py     # Tests GPIO laser/LED/fan
└── test_scanner_app.py      # Tests app d'intégration
```

## Exécution

### Tous les tests
```bash
python -m pytest software/tests/ -v
```

### Tests spécifiques
```bash
python -m pytest software/tests/test_usb_driver.py -v
python -m pytest software/tests/test_motor_control.py -v
```

### Avec couverture de code
```bash
python -m pytest software/tests/ --cov=firmware/raspberry_pi --cov-report=html
```

### Mode verbose
```bash
python -m pytest software/tests/ -v -s
```

## Requirements

```
pytest>=7.0.0
pytest-cov>=3.0.0
pyserial>=3.5
gpiozero>=1.6.0  # optionnel (tests en simulation si non disponible)
```

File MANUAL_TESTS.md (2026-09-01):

# Manual Tests

Practical, copy/paste manual verification steps for HoralScanner hardware
endpoints, to be run directly on the Raspberry Pi against a running
`software/api/horalscanner_api.py` instance (default `http://127.0.0.1:5000`).

See `API_CONTRACT.md` for the exact payload contracts referenced below.

## Fans (0.0, 0.5, 1.0)

```bash
for s in 0.0 0.5 1.0; do
  echo "== speed=$s =="
  curl -sS -X POST http://127.0.0.1:5000/api/fan/creality \
    -H "Content-Type: application/json" -d "{\"speed\": $s}"; echo
  curl -sS -X POST http://127.0.0.1:5000/api/fan/temperature \
    -H "Content-Type: application/json" -d "{\"speed\": $s}"; echo
done
curl -sS http://127.0.0.1:5000/api/fan/status; echo
```

Expected: every call returns `200` with `"success": true`; `/api/fan/status`
reflects the last speed set for each fan.

Rejected payloads (should return `400`):

```bash
curl -i -sS -X POST http://127.0.0.1:5000/api/fan/creality \
  -H "Content-Type: application/json" -d '{"enabled": true}'
curl -i -sS -X POST http://127.0.0.1:5000/api/fan/creality \
  -H "Content-Type: application/json" -d '{"speed": 255}'
```

## Lasers on/off

```bash
curl -sS -X POST http://127.0.0.1:5000/api/laser/left  -H "Content-Type: application/json" -d '{"state": true}'; echo
curl -sS -X POST http://127.0.0.1:5000/api/laser/right -H "Content-Type: application/json" -d '{"state": true}'; echo
curl -sS -X POST http://127.0.0.1:5000/api/laser/left  -H "Content-Type: application/json" -d '{"state": false}'; echo
curl -sS -X POST http://127.0.0.1:5000/api/laser/right -H "Content-Type: application/json" -d '{"state": false}'; echo
curl -sS http://127.0.0.1:5000/api/laser/status; echo
```

Expected: each response includes `"status": {"left": ..., "right": ...}`
matching the requested state.

## RGB colors

```bash
curl -sS -X POST http://127.0.0.1:5000/api/led/color -H "Content-Type: application/json" -d '{"r":255,"g":0,"b":0}'; echo
curl -sS -X POST http://127.0.0.1:5000/api/led/color -H "Content-Type: application/json" -d '{"r":0,"g":255,"b":0}'; echo
curl -sS -X POST http://127.0.0.1:5000/api/led/color -H "Content-Type: application/json" -d '{"r":0,"g":0,"b":255}'; echo
curl -sS -X POST http://127.0.0.1:5000/api/led/color -H "Content-Type: application/json" -d '{"r":0,"g":0,"b":0}'; echo
```

Expected: LED visibly changes color, response echoes the requested
`{"r","g","b"}` values.

## USB camera status/frame

```bash
# List detected V4L2 devices to know which index is real hardware
ls -l /dev/video*
v4l2-ctl --list-devices 2>/dev/null || true

# Raw OpenCV probe (useful to cross-check backend fallback behaviour)
python3 - <<'PY'
import cv2
for i in [0, 1, 2, 3]:
    cap = cv2.VideoCapture(i)
    ok, frame = cap.read()
    print(f"idx {i}: opened={cap.isOpened()} read={ok} shape={None if not ok else frame.shape}")
    cap.release()
PY

# Backend endpoints
curl -sS http://127.0.0.1:5000/api/camera/usb/status; echo
curl -I -sS "http://127.0.0.1:5000/api/camera/usb/frame?t=$(date +%s)"
```

Expected:
- `available: true` in the status response as soon as the hardware is
  readable on *any* of the fallback indices (`0,1,2,3`), even if the
  configured index in `hardware.json`/`camera_config` is wrong.
- `/api/camera/usb/frame` returns HTTP `200` with an `image/jpeg` body.
- Application logs (`journalctl -u horalscanner -n 80 --no-pager` or stdout)
  show a line such as `USB camera: configured device_id=2 failed, falling
  back to working index 0` when a fallback occurred.

## Calibration fallback note

Auto-calibration (`POST /api/camera/calibrate/pose/<camera>` and related
`goto_calibration_pose` flow) can fail on some setups (e.g. LiDAR out of
tolerance, checkerboard not detected). If auto-calibration fails:

1. Use the manual jog controls in the web UI (`Workshop` tab) to move
   X/Y/Z until the target/checkerboard is centered in the camera frame.
2. Use `POST /api/camera/<camera>/save_scan_pose` to persist the manually
   found pose instead of relying on the automatic calibration routine.
3. Re-run `GET /api/camera/<camera>/status` and `.../frame` to confirm the
   camera still reports available/streaming correctly after the manual
   adjustment.

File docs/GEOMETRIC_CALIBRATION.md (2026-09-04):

# Supervised geometric calibration

The geometric wizard calibrates the physical scanner without manufacturing
missing geometry. A real scan remains blocked until every result and its
quality evidence has been accepted.

## Measured fixture and scanner frame

- Checkerboard: **11 × 6 inner corners** (12 × 7 squares), **13 mm** square size.
- The checkerboard center is placed on the center of the measured **200 mm
  diameter** turntable.
- The circumference is derived and recorded as `pi * 200 =
  628.318530717... mm`; the workflow does not silently change any motor
  `rotation_distance`.
- Frame origin: checkerboard/turntable center at the reference pose.
- +X: checkerboard normal at the Y reference; +Y: checkerboard horizontal
  direction/turntable tangent at Y=0; +Z: checkerboard vertical direction and
  turntable axis, upward. The signs relating commanded X and Y to this physical
  frame are estimated from PnP observations, not assumed.

The configured X=195, Y=0, Z=20 mm pose keeps a temporary 5 mm margin from the
first observed mechanical contact at X=200 while preserving the camera framing.
The calibration service hard-caps every trajectory pose at X=195 mm even if an
unsafe higher limit is supplied, and caps calibration Z at the validated 40 mm.
The default 11 poses are:

| View | X (mm) | Y travel (mm / degrees) | Z (mm) |
|---:|---:|---:|---:|
| 1 | 195 | 0 / 0° | 20 |
| 2 | 195 | 0 / 0° | 40 |
| 3 | 185 | 10.4719755 / 6° | 30 |
| 4 | 175 | 20.9439510 / 12° | 40 |
| 5 | 175 | 20.9439510 / 12° | 20 |
| 6 | 165 | 31.4159265 / 18° | 30 |
| 7 | 195 | 41.8879020 / 24° | 20 |
| 8 | 195 | 41.8879020 / 24° | 40 |
| 9 | 165 | 52.3598776 / 30° | 30 |
| 10 | 180 | 62.8318531 / 36° | 40 |
| 11 | 180 | 62.8318531 / 36° | 20 |

Because the checkerboard is centered, a stable Pi-camera checkerboard center is
expected. Diversity is measured from normalized corresponding-corner motion,
centered shape change, scale, orientation, per-corner motion hulls, and unique
views. Center movement is diagnostic only. Status and reports include every
metric and threshold.

After intrinsics, the fixed Pi camera is the primary observable for the shared
mechanism model. Its PnP poses determine the signed X scale and the signed Y
command rotation within the measured 200 mm diameter tolerance. The service
then solves the Pi extrinsic before independently solving and cross-validating
the opposed USB camera against that global scanner-frame model. The USB
camera's commanded Z displacement is removed before fitting its reference
transform. Each USB view evaluates the four proper centered-board adjustments
(identity and 180° about board X, Y, or normal) against a robust rotation
consensus. This normalizes a detector/PnP correspondence-order switch in one
view without allowing a reflection or hiding continuous camera wobble. The
selected global convention and every per-view adjustment/residual are reported.
The fixed Pi observation still defines the canonical board convention; raw
camera-coordinate rotation signs are not compared across cameras.

The USB carriage coefficient is estimated after the fixed Pi-derived signed X
and Y mechanism transform has been applied. At each repeated commanded X/Y
position, the widest 20 mm Z contrast cancels the intercept and X/Y nuisance
motion exactly. With at least three independent contrasts, their multivariate
geometric median is the carriage-vector estimator. This gives bounded influence
to one bad contrast without hiding disagreement: the maximum pairwise
contrast-vector difference is included in the unchanged 0.15 mm/mm
vector-uncertainty gate.
Legacy/custom trajectories without three contrasts retain the prior
Frisch-Waugh-Lovell estimator, which residualizes commanded Z against commanded
X/Y.

The paired trajectory has independent-Z leverage ratio 1.0, four direct
contrasts, eight effective Z samples, and no view contributes more than 0.125 of
the independent-Z information. The former 11-pose trajectory had ratio 0.874
but no direct contrast and concentrated 0.346 of the information in one view.
Across the eight authorized real reports, retaining or excluding the
reference-pose PnP observation then moved the fitted angle across the 12° gate,
while scale stayed near 0.95-0.98 and the centered per-view board-center
sequences differed by only 0.05-0.12 mm RMS. The instability was therefore
support/leverage sensitivity in the within-run estimator, not evidence that a
gate should be relaxed or that independent runs should be averaged.

The fit keeps all views whose joint translation RMS is within the unchanged 5
mm extrinsic limit. Gross translation rejection is deterministic and may remove
a view only when another inlier remains at that same Z level. A PnP mask that
removes a whole Z level fails instead of triggering a biased refit. Calibration
still requires three Z levels spanning 20 mm, independent-Z leverage ratio at
least 0.25, condition number at most 50, per-level repeatability at most 5 mm,
and jackknife carriage-vector deviation at most 0.15 mm per commanded mm.
Residualized legacy fits use leave-one-view and leave-one-level trials. Paired
fits use leave-one-view and leave-one-contrast trials because deleting an entire
endpoint Z level destroys every contrast rather than leaving a valid sample of
the same estimator. Reports include those values, maximum leverage fraction,
effective sample count, per-level sample/inlier counts, rejected views, and
direct same-X/same-Y Z contrasts.

A configured trajectory whose Z is explained by X/Y is rejected before motion
begins. A bad USB fit, ambiguous board convention, out-of-tolerance scale,
insufficient axis travel or Z support, or excessive robust residuals fails
calibration; motor `rotation_distance` is never changed. The fitted signed Y
scale is persisted and used to undo turntable motion during scans. For every
scan frame, runtime derives
the physical turntable center as
`reference_center + signed_x_scale * (current_x - reference_x) * scanner_+X`,
undoes Y rotation about that current center, then maps the result to the
trajectory-origin X center. This prevents pivot warp when automatic centering
moves X from 195 mm to 97.5 mm and also keeps future per-frame X trajectory
changes registered. Missing or inconsistent signed-X/reference metadata blocks
physical scans.

The moving USB fit preserves its complete signed carriage vector rather than
reducing it to a nominal Z direction. On the measured machine the live fit was
approximately `[-0.0117, -0.1742, -0.9370]` mm per commanded Z millimeter
(magnitude `0.953`, vertical alignment `10.557°`). The default vertical
alignment acceptance limit is therefore a measured-machine tolerance of
**12°**; the near-unit scale, regression observability/condition, 5 mm
translation residual, and 3° rotation residual checks remain unchanged.
The captured 35.04° failure contained discrete USB PnP convention switches at
views 8 and 9. Offline normalization recovered
`[-0.0150, -0.1853, -0.9251]`, magnitude about `0.944`, vertical alignment
about `11.36°`, and USB extrinsic residuals about `2.65 mm / 0.53°` with all
11 views. Thus that run was a fit artifact only after the corrected residuals
passed every unchanged safety limit; a normalized result that remains near
35° is still rejected.
TF-Luna is mounted to the same carriage. Its expected calibration readings and
persisted runtime correction use that validated signed USB vector exactly once.

Laser-plane calibration reuses the accepted checkerboard corners for each exact
camera/pose pair. Matched laser-minus-ambient red and chromatic response is
considered only inside an eroded inner-corner polygon, and ambient saturated
spots are excluded. The matched response is reflectance-normalized from the
ambient frame so black/white transitions do not become laser peaks. Bounded
horizontal Gaussian background estimates then remove smooth low-frequency pink
illumination and require a second, finer-scale sharpness response before row
peaks are measured. Each remaining peak needs bilateral local red/chromatic
prominence; its subpixel center and width are measured at half prominence. Rows
with comparable separated peaks are marked
ambiguous rather than allowing the line fit to choose one. A camera/laser
observation is accepted only when the resulting peaks form one thin, continuous
line with sufficient span and low image-line residual. A robust row fit may
discard isolated outlier rows or one short outlier segment. The strict unexplained
gap limit remains unchanged. An interval bounded by consecutive
perspective-projected checker rows may be bridged only when adjacent local line
fits independently meet the unchanged 2 px residual limit. Their combined
observed points and each segment relative to that line must also remain within
2 px, and the two segments' mean offsets may differ by at most 2 px. This
rejects a shifted segment without letting one checker-boundary localization
sample veto an otherwise coherent ridge. That pairwise line—not either noisy
short-segment slope—is used to intersect projected checker boundaries and
sample the gap; no local slope is extrapolated across the unobserved cell.
Alternating checker
reflectance must confirm the dark cell from both neighboring cells. The missing
cell may contain either low response or a centered, narrow, chromatic
subthreshold ridge. That evidence is evaluated at one co-located peak per row;
the strongest qualified sharp/chromatic peak is selected rather than the
strongest raw response. At least three consecutive rows must support the
centerline. An off-axis peak counts as a competitor only when its own co-located
response is comparably strong, sharp, and chromatic for at least three
consecutive rows. Isolated or stronger grayscale checker artifacts therefore
cannot mask a real centerline, while shifted, broad-halo, and competing ridges
remain rejected. In the gap-only path, an off-axis run is explained as a checker
edge only when it remains on one projected checker column for three rows, the
ambient edge has the existing minimum checker contrast, the response is within
the unchanged 2 px geometry residual, and that column lies beyond the existing
line-width core. A nearby ridge that does not track the checker edge remains a
competitor. Adjacent segments must span at least 35% of the local projected
pitch, which keeps sparse stubs out while supporting perspective-shortened edge
segments. Non-checker gaps,
two-square gaps, segment jumps, reflections, and edge-only hits are recorded and
skipped. Compact
per-view diagnostics report raw and unexplained maximum gaps, bridged checker
gaps, projected pitch/limit aggregates, segment/outlier counts, raw candidate
pixels, background-suppressed candidates, peak prominence, ambiguous rows, and
local width percentiles; images and per-row arrays are not embedded. Reflections
on the wall, platform, mount, or laser housing are never intersected with the
board plane. Because both laser modules are physically on the Pi Camera V3 NoIR
side, each laser plane is fitted only from valid Pi-camera on-board lines. USB
observations retain the same strict diagnostics and, when
they independently satisfy all point/view/orientation requirements, cross-check
the Pi plane without contributing samples to it. Each laser must still provide
at least the configured number of Pi points across three valid poses and three
independently oriented board views before the robust plane fit, and both the
plane RMS and optional USB cross-validation RMS limits remain **2 mm**. Laser
ambient and laser-on frames are captured under one Pi Camera photometric setting
per pose. With both lasers off, automatic exposure, analogue gain, and white
balance settle for `laser_photometric_settle_s` (default **1 second**); their
effective public Picamera2 metadata values are then locked and confirmed before
the ambient and both laser frames. Every exact image request must report matching
`ExposureTime`, `AnalogueGain`, and two-channel `ColourGains`; missing or drifting
numeric metadata rejects the observation. `AwbEnable` is also rejected when it
is reported as true, but Raspberry Pi OS libcamera stacks that omit this
input-state field are accepted only when the required colour gains remain
present and numerically locked across all frames. Failures list the relevant
metadata keys and values returned by the camera. The prior automatic/manual
controls are restored in a `finally` guard on success, failure, or cancellation. Missing Pi
controls fail preflight before laser-plane acquisition. A USB camera participates
in the optional laser cross-check only when a verified matched-photometry capture
path exists. The current OpenCV USB driver does not provide a portable exposure
lock, so the report records that diagnostic and the Pi-authoritative fit
continues. Laser
control remains binary at the API boundary, but the tracked production hardware
configuration opts GPIO27 and GPIO22 into 1 kHz `PWMOutputDevice` control at a
conservative 20% calibration duty. The calibration service selects that fixed,
bounded profile internally; callers cannot submit an arbitrary duty cycle.
Configurations without `lasers.pwm_enabled: true` retain the previous digital
full-power behavior for backward compatibility. Do not weaken the line width,
point, pose, orientation, spread, or 2 mm plane-fit gates to compensate for
optical saturation.

Before the final point-level robust fit, laser-plane calibration now runs a
deterministic, bounded, pose-balanced consensus. It forms at most 128 hypotheses
from the global pose set and pose pairs, with at most 64 evenly distributed
points from each pose. If exhaustive global/pair coverage would exceed the
configured bound, calibration fails closed rather than sampling hypotheses and
potentially missing a competing plane. A hypothesis is scored independently against every
originally accepted Pi pose. A pose contributes only when at least the
configured points and 75% of all its points lie within the fixed 2 mm residual
threshold. Thus one dense pose cannot dominate the score and a small arbitrary
subset cannot preserve a bad pose. The retained set must contain at least 75%
of the originally accepted poses, may reject at most 25%, and must still contain
at least three poses and three independently oriented boards. The final robust
fit is pose-balanced, retains the existing two-dimensional spread check, and
must itself remain at or below 2 mm RMS. No subset passing only weaker limits is
accepted.

Competing hypotheses with similarly sized, substantially distinct pose support
are compared before selection. If their normals differ by at least 3 degrees or
their canonical offsets differ by at least 2 mm, calibration fails as ambiguous
instead of selecting either plane. Reports include the bounded hypothesis count,
all consensus thresholds, original/retained/rejected pose fractions, per-pose
residual RMS/median/p90/p95/maximum and surviving-point fraction, explicit
rejection reasons, and leave-one-pose-out training/held-out RMS plus plane
normal/offset deltas.

Calibration payload validation requires this Pi-authoritative provenance and
the complete unambiguous pose-consensus evidence, surviving per-pose point
counts, view/orientation counts, and two-dimensional spread condition. A legacy
laser plane without that evidence is intentionally rejected and must be
recalibrated; it is not silently trusted after upgrade. Persistence prepares
the report and rollback backup, renames them, and syncs the parent directory
before atomically switching the active calibration file and syncing the
directory again. Runtime installation is part of the same non-cancellable
transaction; an installation failure restores both the complete previous disk
generation and runtime calibration. Cancellation is checked immediately before
this transaction and a later request waits for activation rather than reporting
a false cancelled outcome.
The workflow suspends TF-Luna ranging output once before checkerboard camera
capture, waits for the optical spot to clear, and restores ranging output in a
`finally` guard before any LiDAR measurements. Cancellation and failure paths
also restore output. The workflow rejects the pose if both cameras do not detect
a fresh checkerboard view with at least the configured 2% inner-corner frame
margin and 3% image coverage.
Calibration accepts only the configured 11 × 6 pattern;
a 10 × 6 subset detection is explicitly rejected.
Detection first uses the fast classic OpenCV detector, which normally detects
this board despite the TF-Luna spot. The sector-based detector is only a
bounded fallback. Each bounded attempt also tries histogram equalization before
the sector-based detector, which recovers the low-contrast Logitech C270 view.
If these fail, one small saturated blue IR blob may be masked and inpainted
before a final retry; broad white board regions are never masked. This only
protects corner detection—the IR spot is not used as geometric evidence. Any
result whose glare mask overlaps a detected corner remains rejected. Framing
failures report the measured edge margin or coverage separately from detector
failures. The workflow does not require the absent RGB LED.
Calibration allows up to 8 seconds for each ARM checkerboard attempt and
retries up to three fresh frames, accepting the first exact 11 × 6 result.
Both cameras share a bounded 35-second framing deadline at each pose; a single
timed-out frame does not abort the run, and cancellation is checked while
OpenCV detection is pending. Normal camera API deadlines are unchanged.

## Before supervised motion

Deploy in a single hardware-owning process. With the API stopped, update the
checkout, install existing dependencies, validate syntax/tests, and restart:

```bash
cd /opt/horalscanner
git fetch origin
git checkout main
git pull --ff-only origin main
python3 -m pip install -r requirements.txt
python3 -m py_compile software/api/checkerboard_detector.py \
  software/api/geometric_calibration.py software/api/lidar_driver.py
sudo systemctl restart horalscanner
sudo systemctl status --no-pager horalscanner
```

These checks do not command motion or energize a laser:

```bash
curl -fsS http://127.0.0.1:5000/api/status | python3 -m json.tool
curl -fsS http://127.0.0.1:5000/api/calibration/geometric/status | python3 -m json.tool
curl -fsS -X POST -H 'Content-Type: application/json' \
  -d '{"start_pose":{"x":195,"y":0,"z":20},"lidar_measurements":{"origin_mm":[MEASURE_X,MEASURE_Y,MEASURE_Z],"direction":[DIR_X,DIR_Y,DIR_Z],"reference_z_mm":20}}' \
  http://127.0.0.1:5000/api/calibration/geometric/preflight | python3 -m json.tool
```

Replace every `MEASURE_*`/`DIR_*` token with independently measured TF-Luna
beam geometry in the scanner frame. Range readings alone cannot determine the
full transform.

## Supervised run

Home X/Y/Z using the existing controls first. Center and secure the board,
clear the full travel envelope, provide an accessible emergency stop, and
keep an operator present. Prefer the web wizard. The equivalent start request
is:

```bash
curl -fsS -X POST -H 'Content-Type: application/json' \
  -d '{"start_pose":{"x":195,"y":0,"z":20},"lidar_measurements":{"origin_mm":[MEASURE_X,MEASURE_Y,MEASURE_Z],"direction":[DIR_X,DIR_Y,DIR_Z],"reference_z_mm":20}}' \
  http://127.0.0.1:5000/api/calibration/geometric/start | python3 -m json.tool
watch -n 1 'curl -fsS http://127.0.0.1:5000/api/calibration/geometric/status'
```

Emergency software cancellation always requests a motor stop and both lasers
off:

```bash
curl -fsS -X POST http://127.0.0.1:5000/api/calibration/geometric/cancel
curl -fsS http://127.0.0.1:5000/api/calibration/geometric/report?download=1 \
  -o horalscanner-calibration-report.json
```
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

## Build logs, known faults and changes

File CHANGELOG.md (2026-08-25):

# Changelog

All notable changes to HoralScanner are documented in this file.

## [1.0.0] - 2026-08-23

### Added

**Web Dashboard UI**
- Single-page application served at `GET /` from `software/web/index.html`
- Real-time controls: laser toggles, LED RGB color picker, motor sliders, fan speed sliders
- Live temperature display and motor position readout
- Polling-based live updates (5-second interval)
- Responsive, mobile-friendly layout

**API Enhancements**
- `GET /` → serves `software/web/index.html`
- `GET /api/status` → health check (API, GPIO driver, STM32 driver availability)
- `GET /api/laser/status` → current laser states
- `GET /api/led/status` → current LED color
- CORS headers on all responses (`Access-Control-Allow-Origin: *`)
- Static file serving from `software/web/`

**Fan Control**
- `POST /api/fan/pi` — Pi GPIO23 fan output (0 = off, any positive value = on)
- `POST /api/fan/creality` — Creality PA0 fan PWM
- `POST /api/fan/temperature` — Temperature PA8 fan PWM
- `GET /api/fan/status` — aggregated fan status
- Accepts `speed` (0–1), `pwm` (0–1), or `percent` (0–100)

**Temperature Monitoring**
- `GET /api/temperature/board` — STM32 board temperature (PC5)
- `GET /api/temperature/all` — all temperature data

**Drivers**
- `STM32Driver`: fan state tracking (PA0, PA8), `get_fan_status()`, `read_board_temperature()`
- `GPIODriver`: Pi fan digital output on GPIO23

**Documentation**
- `DEPLOYMENT.md` — installation and systemd service instructions
- `USAGE.md` — web UI guide and full API reference
- `hardware/wiring_diagram.md` — updated with PA0, PA8, PC5 pin mapping

### Known Issues

- `GET /api/temperature/board` returns an error when the STM32 is not physically connected
  (PC5 ADC read over USB requires live hardware).
- The development server (`flask run`) is not recommended for production; use a WSGI server.

[1.0.0]: https://github.com/jose33bro/horaltscanner/releases/tag/v1.0.0

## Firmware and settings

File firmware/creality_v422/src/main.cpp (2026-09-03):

#include <Arduino.h>
#include <math.h>
#include <stdlib.h>
#include <string.h>

namespace {

constexpr uint32_t SERIAL_BAUD = 115200;
constexpr uint32_t COMMAND_TIMEOUT_MS = 5000;
constexpr uint32_t HOME_TIMEOUT_MS = 120000;
constexpr uint32_t Y_INDEX_DEBOUNCE_MS = 20;
constexpr uint32_t MAX_MOVE_STEPS = 200000;
constexpr uint32_t MIN_STEP_RATE = 1;
constexpr uint32_t MAX_STEP_RATE = 20000;
constexpr uint16_t STEP_PULSE_US = 4;

constexpr uint32_t ENABLE_PIN = PC3;
constexpr uint32_t HEATER_0_PIN = PA1;
constexpr uint32_t HEATER_BED_PIN = PA2;
constexpr uint32_t FAN_PA0_PIN = PA0;
constexpr uint32_t FAN_PA8_PIN = PA8;
constexpr uint32_t TEMP_PC5_PIN = PC5;

struct Axis {
  char name;
  uint32_t step_pin;
  uint32_t dir_pin;
  uint32_t endstop_pin;
  bool direction_inverted;
  bool endstop_active_high;
  uint32_t start_step_rate;
  uint32_t home_step_rate;
};

constexpr Axis AXES[] = {
    {'X', PC2, PB9, PA5, false, true, 100, 400},
    {'Y', PB8, PB7, PA6, true, true, 20, 100},
    {'Z', PB6, PB5, PA7, true, true, 100, 400},
};
constexpr size_t AXIS_COUNT = sizeof(AXES) / sizeof(AXES[0]);

char command_buffer[96];
size_t command_length = 0;
uint8_t fan_pa0 = 0;
uint8_t fan_pa8 = 0;
uint32_t last_command_ms = 0;
bool steppers_enabled = false;

enum class MotionType { IDLE, MOVE, HOME };
enum class MotionResult { DONE, RUNNING, STOPPED, ERROR };
enum class YHomePhase { SEEK_RELEASE, SEEK_TRIGGER };

MotionType motion_type = MotionType::IDLE;
MotionResult motion_result = MotionResult::DONE;
const Axis *motion_axis = nullptr;
uint32_t motion_steps_remaining = 0;
uint32_t motion_steps_completed = 0;
uint32_t motion_period_us = 0;
uint32_t motion_start_rate = 0;
uint32_t motion_target_rate = 0;
uint32_t motion_ramp_steps = 1;
uint32_t motion_next_edge_us = 0;
uint32_t motion_deadline_ms = 0;
uint8_t home_axis_index = 0;
bool home_all = false;
bool motion_positive = false;
bool step_pin_high = false;
YHomePhase y_home_phase = YHomePhase::SEEK_TRIGGER;
bool y_index_candidate = false;
uint32_t y_index_candidate_since_ms = 0;

Axis const *findAxis(char name) {
  for (const Axis &axis : AXES) {
    if (axis.name == name) return &axis;
  }
  return nullptr;
}

void setSteppersEnabled(bool enabled) {
  digitalWrite(ENABLE_PIN, enabled ? LOW : HIGH);
  steppers_enabled = enabled;
}

bool endstopTriggered(const Axis &axis) {
  return digitalRead(axis.endstop_pin) == (axis.endstop_active_high ? HIGH : LOW);
}

void setDirection(const Axis &axis, bool positive) {
  const bool high = positive ^ axis.direction_inverted;
  digitalWrite(axis.dir_pin, high ? HIGH : LOW);
}

void serviceFanPa0() {
  static uint32_t cycle_started_us = 0;
  const uint32_t now = micros();
  const uint32_t elapsed = now - cycle_started_us;
  if (elapsed >= 10000) cycle_started_us = now;
  const uint32_t on_time_us = static_cast<uint32_t>(fan_pa0) * 10000U / 255U;
  digitalWrite(FAN_PA0_PIN, fan_pa0 > 0 && (now - cycle_started_us) < on_time_us);
}

void finishMotion(MotionResult result);

void serviceSafety() {
  serviceFanPa0();
  if (motion_type != MotionType::IDLE &&
      millis() - last_command_ms > COMMAND_TIMEOUT_MS) {
    finishMotion(MotionResult::ERROR);
  }
}

void finishMotion(MotionResult result) {
  if (motion_axis) digitalWrite(motion_axis->step_pin, LOW);
  setSteppersEnabled(false);
  motion_type = MotionType::IDLE;
  motion_result = result;
  motion_axis = nullptr;
  step_pin_high = false;
}

void updateMotionPeriod() {
  uint32_t ramp_position = min(motion_steps_completed + 1, motion_ramp_steps);
  if (motion_type == MotionType::MOVE) {
    ramp_position = min(ramp_position, motion_steps_remaining + 1);
  }
  const uint32_t rate_delta = motion_target_rate - motion_start_rate;
  const uint32_t rate =
      motion_start_rate + (rate_delta * ramp_position) / motion_ramp_steps;
  motion_period_us = 1000000U / (rate == 0 ? 1 : rate);
}

void beginHomeAxis(uint8_t index) {
  home_axis_index = index;
  motion_axis = &AXES[index];
  const bool endstop_triggered = endstopTriggered(*motion_axis);
  if (motion_axis->name != 'Y' && endstop_triggered) {
    if (home_all && static_cast<size_t>(index + 1) < AXIS_COUNT) {
      beginHomeAxis(index + 1);
    } else {
      finishMotion(MotionResult::DONE);
    }
    return;
  }
  setDirection(*motion_axis, false);
  motion_steps_completed = 0;
  motion_start_rate = motion_axis->start_step_rate;
  motion_target_rate = motion_axis->home_step_rate;
  motion_ramp_steps = 100;
  updateMotionPeriod();
  motion_next_edge_us = micros();
  motion_deadline_ms = millis() + HOME_TIMEOUT_MS;
  motion_type = MotionType::HOME;
  motion_result = MotionResult::RUNNING;
  step_pin_high = false;
  y_home_phase =
      endstop_triggered ? YHomePhase::SEEK_RELEASE : YHomePhase::SEEK_TRIGGER;
  y_index_candidate = false;
  setSteppersEnabled(true);
}

bool beginMove(const Axis &axis, int32_t steps, uint32_t rate) {
  if (motion_type != MotionType::IDLE || steps == 0) return steps == 0;
  motion_axis = &axis;
  motion_positive = steps > 0;
  motion_steps_remaining = static_cast<uint32_t>(labs(steps));
  motion_steps_completed = 0;
  motion_start_rate = min(axis.start_step_rate, rate);
  motion_target_rate = rate;
  motion_ramp_steps = motion_steps_remaining / 2U;
  if (motion_ramp_steps == 0) motion_ramp_steps = 1;
  if (motion_ramp_steps > 100) motion_ramp_steps = 100;
  updateMotionPeriod();
  motion_next_edge_us = micros();
  motion_type = MotionType::MOVE;
  motion_result = MotionResult::RUNNING;
  last_command_ms = millis();
  step_pin_high = false;
  setDirection(axis, motion_positive);
  setSteppersEnabled(true);
  return true;
}

bool beginHome(const Axis *axis) {
  if (motion_type != MotionType::IDLE) return false;
  last_command_ms = millis();
  home_all = axis == nullptr;
  beginHomeAxis(axis ? static_cast<uint8_t>(axis - AXES) : 0);
  return true;
}

void serviceMotion() {
  if (motion_type == MotionType::IDLE || motion_axis == nullptr) return;

  if (motion_type == MotionType::HOME) {
    bool axis_homed = false;
    if (motion_axis->name == 'Y') {
      const uint32_t now_ms = millis();
      const bool expected_triggered = y_home_phase == YHomePhase::SEEK_TRIGGER;
      if (endstopTriggered(*motion_axis) != expected_triggered) {
        y_index_candidate = false;
      } else if (!y_index_candidate) {
        y_index_candidate = true;
        y_index_candidate_since_ms = now_ms;
      } else if (now_ms - y_index_candidate_since_ms >= Y_INDEX_DEBOUNCE_MS) {
        if (y_home_phase == YHomePhase::SEEK_RELEASE) {
          y_home_phase = YHomePhase::SEEK_TRIGGER;
          y_index_candidate = false;
        } else {
          axis_homed = true;
        }
      }
    } else {
      axis_homed = endstopTriggered(*motion_axis);
    }

    if (axis_homed) {
      digitalWrite(motion_axis->step_pin, LOW);
      step_pin_high = false;
      if (home_all && static_cast<size_t>(home_axis_index + 1) < AXIS_COUNT) {
        beginHomeAxis(home_axis_index + 1);
      } else {
        finishMotion(MotionResult::DONE);
      }
      return;
    }
    if (static_cast<int32_t>(millis() - motion_deadline_ms) >= 0) {
      finishMotion(MotionResult::ERROR);
      return;
    }
  } else if (motion_axis->name != 'Y' && !motion_positive &&
             endstopTriggered(*motion_axis)) {
    finishMotion(MotionResult::DONE);
    return;
  }

  const uint32_t now = micros();
  if (static_cast<int32_t>(now - motion_next_edge_us) < 0) return;

  if (!step_pin_high) {
    if (motion_type == MotionType::MOVE && motion_steps_remaining == 0) {
      finishMotion(MotionResult::DONE);
      return;
    }
    digitalWrite(motion_axis->step_pin, HIGH);
    step_pin_high = true;
    motion_next_edge_us = now + STEP_PULSE_US;
  } else {
    digitalWrite(motion_axis->step_pin, LOW);
    step_pin_high = false;
    if (motion_type == MotionType::MOVE) --motion_steps_remaining;
    ++motion_steps_completed;
    updateMotionPeriod();
    motion_next_edge_us =
        now + (motion_period_us > STEP_PULSE_US ? motion_period_us - STEP_PULSE_US : 1);
  }
}

bool parseLong(const char *text, long &value) {
  if (!text || !*text) return false;
  char *end = nullptr;
  value = strtol(text, &end, 10);
  return end && *end == '\0';
}

void printError(const char *message) {
  Serial1.print("ERR ");
  Serial1.println(message);
}

void printTemperature() {
  constexpr float SERIES_RESISTOR_OHMS = 4700.0f;
  constexpr float NOMINAL_RESISTANCE_OHMS = 100000.0f;
  constexpr float NOMINAL_TEMP_K = 25.0f + 273.15f;
  constexpr float BETA = 4092.0f;

  const uint32_t adc = analogRead(TEMP_PC5_PIN);
  if (adc <= 1 || adc >= 4094) {
    printError("TEMP_SENSOR");
    return;
  }
  const float resistance = SERIES_RESISTOR_OHMS * adc / (4095.0f - adc);
  const float inverse_temp =
      (1.0f / NOMINAL_TEMP_K) + logf(resistance / NOMINAL_RESISTANCE_OHMS) / BETA;
  const float celsius = (1.0f / inverse_temp) - 273.15f;
  if (!isfinite(celsius) || celsius < -50.0f || celsius > 150.0f) {
    printError("TEMP_RANGE");
    return;
  }
  Serial1.print("OK TEMP_PC5 ");
  Serial1.println(celsius, 1);
}

void processCommand(char *line) {
  char *verb = strtok(line, " ");
  if (!verb) return;

  if (strcmp(verb, "PING") == 0) {
    Serial1.println("OK PONG");
    return;
  }

  if (strcmp(verb, "MOVE") == 0) {
    const char *axis_text = strtok(nullptr, " ");
    const char *steps_text = strtok(nullptr, " ");
    const char *rate_text = strtok(nullptr, " ");
    long steps = 0;
    long rate = 0;
    const Axis *axis = axis_text && axis_text[1] == '\0' ? findAxis(axis_text[0]) : nullptr;
    if (!axis || !parseLong(steps_text, steps) || !parseLong(rate_text, rate) ||
        steps < -static_cast<long>(MAX_MOVE_STEPS) ||
        steps > static_cast<long>(MAX_MOVE_STEPS) ||
        rate < static_cast<long>(MIN_STEP_RATE) ||
        rate > static_cast<long>(MAX_STEP_RATE) ||
        !beginMove(*axis, static_cast<int32_t>(steps), static_cast<uint32_t>(rate))) {
      printError("MOVE");
      return;
    }
    Serial1.println("OK MOVE");
    return;
  }

  if (strcmp(verb, "HOME") == 0) {
    const char *axis_text = strtok(nullptr, " ");
    if (!axis_text) {
      printError("HOME");
      return;
    }
    const bool all = strcmp(axis_text, "ALL") == 0;
    const Axis *axis = !all && axis_text[1] == '\0' ? findAxis(axis_text[0]) : nullptr;
    if ((!all && !axis) || !beginHome(all ? nullptr : axis)) {
      printError("HOME");
      return;
    }
    Serial1.println("OK HOME");
    return;
  }

  if (strcmp(verb, "ENDSTOP") == 0) {
    const char *axis_text = strtok(nullptr, " ");
    const Axis *axis = axis_text && axis_text[1] == '\0' ? findAxis(axis_text[0]) : nullptr;
    if (!axis) {
      printError("ENDSTOP");
      return;
    }
    Serial1.print("OK ENDSTOP ");
    Serial1.println(endstopTriggered(*axis) ? 1 : 0);
    return;
  }

  if (strcmp(verb, "SYNC") == 0) {
    const char *token = strtok(nullptr, " ");
    if (!token) {
      printError("SYNC");
      return;
    }
    Serial1.print("OK SYNC ");
    Serial1.println(token);
    return;
  }

  if (strcmp(verb, "STOP") == 0) {
    finishMotion(MotionResult::STOPPED);
    Serial1.println("OK STOP");
    return;
  }

  if (strcmp(verb, "MOTION_STATUS") == 0) {
    if (motion_result == MotionResult::RUNNING) last_command_ms = millis();
    Serial1.print("OK MOTION_STATUS ");
    switch (motion_result) {
      case MotionResult::RUNNING: Serial1.println("RUNNING"); break;
      case MotionResult::STOPPED: Serial1.println("STOPPED"); break;
      case MotionResult::ERROR: Serial1.println("ERROR"); break;
      default: Serial1.println("DONE"); break;
    }
    return;
  }

  if (strcmp(verb, "FAN_PA0_PWM") == 0 || strcmp(verb, "FAN_PA8_PWM") == 0) {
    const bool pa0 = strcmp(verb, "FAN_PA0_PWM") == 0;
    const char *value_text = strtok(nullptr, " ");
    long value = 0;
    if (!parseLong(value_text, value) || value < 0 || value > 255) {
      printError("FAN");
      return;
    }
    if (pa0) {
      fan_pa0 = static_cast<uint8_t>(value);
    } else {
      fan_pa8 = static_cast<uint8_t>(value);
      analogWrite(FAN_PA8_PIN, fan_pa8);
    }
    Serial1.println(pa0 ? "OK FAN_PA0_PWM" : "OK FAN_PA8_PWM");
    return;
  }

  if (strcmp(verb, "TEMP_PC5_READ") == 0) {
    printTemperature();
    return;
  }

  printError("UNKNOWN_COMMAND");
}

}  // namespace

void setup() {
  pinMode(ENABLE_PIN, OUTPUT);
  pinMode(HEATER_0_PIN, OUTPUT);
  pinMode(HEATER_BED_PIN, OUTPUT);
  pinMode(FAN_PA0_PIN, OUTPUT);
  pinMode(FAN_PA8_PIN, OUTPUT);
  digitalWrite(HEATER_0_PIN, LOW);
  digitalWrite(HEATER_BED_PIN, LOW);
  digitalWrite(FAN_PA0_PIN, LOW);
  digitalWrite(FAN_PA8_PIN, LOW);
  setSteppersEnabled(false);

  for (const Axis &axis : AXES) {
    pinMode(axis.step_pin, OUTPUT);
    pinMode(axis.dir_pin, OUTPUT);
    pinMode(axis.endstop_pin, INPUT_PULLUP);
    digitalWrite(axis.step_pin, LOW);
  }

  analogReadResolution(12);
  analogWriteResolution(8);
  Serial1.begin(SERIAL_BAUD);
  last_command_ms = millis();
}

void loop() {
  serviceSafety();
  serviceMotion();
  while (Serial1.available()) {
    const char value = static_cast<char>(Serial1.read());
    if (value == '\n' || value == '\r') {
      if (command_length > 0) {
        command_buffer[command_length] = '\0';
        processCommand(command_buffer);
        command_length = 0;
      }
    } else if (command_length < sizeof(command_buffer) - 1) {
      command_buffer[command_length++] = value;
    } else {
      command_length = 0;
      printError("COMMAND_TOO_LONG");
    }
  }
}

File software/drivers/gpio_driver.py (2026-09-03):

"""GPIO driver for HoralScanner lasers, LED, and fans.

Supports a *simulation* mode (no hardware required) used by the test suite.
"""
from __future__ import annotations

import logging
import math
import threading
from pathlib import Path
from typing import Callable

logger = logging.getLogger(__name__)

_DEFAULT_HARDWARE_CONFIG: dict = {
    "lasers": {
        "left": {"gpio": 17, "active_high": True},
        "right": {"gpio": 27, "active_high": True},
    },
    "led_rgb": {
        "active_high": True,
        "pwm_frequency_hz": 100,
        "red": {"gpio": 22},
        "green": {"gpio": 23},
        "blue": {"gpio": 24},
    },
    "fans": {
        "pi_fan": {
            "gpio": 18,
            "active_high": True,
            "default_value": 0,
            "auto_control": False,
            "on_temp_c": 55,
            "off_temp_c": 45,
        }
    },
}

_LED_MODES = {"off", "on", "pulse"}
_LASER_SIDES = ("left", "right")
_LASER_POWER_PROFILES = ("default", "calibration", "scan")


class GPIODriver:
    """GPIO driver with optional simulation mode."""

    def __init__(
        self,
        simulation: bool = False,
        hardware_config: dict | None = None,
        output_device_factory: Callable | None = None,
        pwm_device_factory: Callable | None = None,
        temperature_reader: Callable | None = None,
        cpu_temperature_reader: Callable[[], float | None] | None = None,
    ) -> None:
        cfg_in = hardware_config or {}

        lasers_cfg = cfg_in.get("lasers", _DEFAULT_HARDWARE_CONFIG["lasers"])
        led_cfg = cfg_in.get("led_rgb", _DEFAULT_HARDWARE_CONFIG["led_rgb"])
        fans_cfg = cfg_in.get("fans", _DEFAULT_HARDWARE_CONFIG["fans"])
        pi_fan_cfg: dict = fans_cfg.get("pi_fan", _DEFAULT_HARDWARE_CONFIG["fans"]["pi_fan"])

        on_temp = pi_fan_cfg.get("on_temp_c", 55)
        off_temp = pi_fan_cfg.get("off_temp_c", 45)
        if on_temp <= off_temp:
            raise ValueError(
                f"on_temp_c ({on_temp}) must be greater than off_temp_c ({off_temp})"
            )

        self._simulation = simulation
        self._hardware_config = dict(cfg_in)
        self._output_device_factory = output_device_factory
        self._pwm_device_factory = pwm_device_factory
        self._temperature_reader = temperature_reader
        self._cpu_temperature_reader = cpu_temperature_reader or self._read_cpu_temperature
        self._laser_lock = threading.RLock()

        self._pin_laser_left: int = lasers_cfg.get("left", {}).get("gpio", 17)
        self._pin_laser_right: int = lasers_cfg.get("right", {}).get("gpio", 27)
        self._pin_led_r: int = led_cfg.get("red", {}).get("gpio", 22)
        self._pin_led_g: int = led_cfg.get("green", {}).get("gpio", 23)
        self._pin_led_b: int = led_cfg.get("blue", {}).get("gpio", 24)
        self._pin_fan_pi: int = pi_fan_cfg.get("gpio", 18)
        self._laser_pwm_enabled = bool(lasers_cfg.get("pwm_enabled", False))
        self._laser_pwm_frequency_hz: float | None = None
        self._laser_powers: dict[str, dict[str, float]] = {}
        self._configure_laser_power(lasers_cfg)

        self._pi_fan_on_temp: float = float(on_temp)
        self._pi_fan_off_temp: float = float(off_temp)
        self._pi_fan_auto: bool = pi_fan_cfg.get("auto_control", False)
        self._pi_fan_fan_on: bool = False

        self._hardware_available = False
        self._last_error: Exception | None = None
        self._laser_left_device = None
        self._laser_right_device = None
        self._led_r_device = None
        self._led_g_device = None
        self._led_b_device = None
        self._fan_device = None

        self._laser_status = {"left": False, "right": False}
        self._led_status = {"r": 0, "g": 0, "b": 0}
        self._pi_fan_speed: float = float(pi_fan_cfg.get("default_value", 0))

    # ------------------------------------------------------------------
    # Connection / lifecycle
    # ------------------------------------------------------------------

    @property
    def simulation(self) -> bool:
        return self._simulation

    @property
    def hardware_available(self) -> bool:
        return self._hardware_available

    @property
    def last_error(self) -> Exception | None:
        """Last exception raised while attempting to connect, if any."""
        return self._last_error
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

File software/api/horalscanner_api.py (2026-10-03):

"""HoralScanner Flask API (modern version)."""

from __future__ import annotations

import copy
import json
import logging
import math
import sys
import threading
import time
from functools import wraps
from io import BytesIO
from pathlib import Path
from typing import Any, Callable

# Add repo root to path so 'software' module can be imported
_API_DIR = Path(__file__).resolve().parent
_SOFTWARE_DIR = _API_DIR.parent
_REPO_ROOT = _API_DIR.parent.parent
sys.path.insert(0, str(_REPO_ROOT))
sys.path.insert(0, str(_SOFTWARE_DIR))

# Modern Flask imports
from flask import (
    Blueprint,
    Flask,
    Response,
    g,
    has_request_context,
    jsonify,
    request,
    send_file,
    send_from_directory,
)

# Blueprint moderne
api_bp = Blueprint("api", __name__)

# Modern API imports
try:
    from . import config_manager
except ImportError:  # pragma: no cover - direct script execution
    from software.api import config_manager
from software.api.camera_calibration import (
    get_all_saved_poses,
    get_calibration_pose,
    get_saved_pose,
    move_to_calibration_pose,
    restore_scan_pose,
    save_current_pose,
)
from software.api.camera_driver import (
    LogitechCamera,
    PiCamera,
    analyze_camera_frame,
    analyze_laser_line,
)
from software.api.calibration_pose import (
    PoseMemory,
    get_default_pose,
    move_to_pose,
    read_lidar_distance,
)
from software.api.lidar_driver import LidarDriver
from software.api.hardware_lock import HardwareReservationLock
from software.api.geometric_calibration import (
    AtomicCalibrationStore,
    CalibrationError,
    GeometricCalibrationService,
    normalize_laser_sides,
)
from software.api.scanner_engine import (
    ReconstructionEngine,
    ScanPreflightError,
    ScanSession,
    _O3D_AVAILABLE,
)
from api.services import scan_service

logger = logging.getLogger(__name__)

# Drivers
try:
    from software.drivers.stm32_driver import STM32Driver
except Exception as exc:  # pragma: no cover - environment dependent
    STM32Driver = None  # type: ignore[assignment]
    logger.warning("STM32Driver import failed: %s", exc)

try:
    from software.drivers.gpio_driver import GPIODriver
except Exception as exc:  # pragma: no cover - environment dependent
    GPIODriver = None  # type: ignore[assignment]
    logger.warning("GPIODriver import failed: %s", exc)

_WEB_DIR = _API_DIR.parent / "web"
_VERSION_FILE = _REPO_ROOT / "VERSION"
_VERSION = _VERSION_FILE.read_text().strip() if _VERSION_FILE.exists() else "unknown"

# Calibration poses for each camera.
# Pi Camera: X/Y only (Z must not be changed automatically).
# Logitech USB: X/Y/Z (Z used for height).
CAMERA_CALIBRATION_POSES: dict[str, dict[str, float | None]] = {
    "pi": {"x": 0.0, "y": 0.0, "z": None},
    "usb": {"x": 0.0, "y": 0.0, "z": 50.0},
}

# In-memory scan pose memory.  Populated when a calibration pose is reached.
_scan_pose: dict[str, Any] | None = None


@api_bp.after_request
def _add_cors(response):
    response.headers["Access-Control-Allow-Origin"] = "*"
    response.headers["Access-Control-Allow-Headers"] = "Content-Type"
    response.headers["Access-Control-Allow-Methods"] = "GET, POST, OPTIONS"
    return response


@api_bp.before_request
def _guard_scan_hardware_reservation():
    """Prevent manual controls from racing a physical acquisition."""
    allowed = {"/api/motor/stop", "/api/motor/status"}
    guarded = (
        request.path.startswith((
            "/api/move/",
            "/api/home/",
            "/api/rotate",
            "/api/laser/",
            "/api/camera/",
            "/api/lidar/",
        ))
        or (
            request.method == "POST"
            and request.path.startswith("/api/scan/pose/")
        )
        or (
            request.method == "POST"
            and request.path == "/api/scan/preflight"
        )
    )
    if request.path in allowed or not guarded:
        return None

    session = globals().get("scan_session")
    reservation = globals().get("_scan_hardware_lock")
    if (
        session is not None
        and bool(getattr(session, "hardware_reserved", False))
    ) or reservation is None or not reservation.acquire(blocking=False):
        return _json_error(
            "Scanner hardware is reserved by an active acquisition",
            409,
            hint="Stop the scan before using manual motor, laser, camera, or LiDAR controls.",
        )
    g.scan_hardware_lock_acquired = True
    return None


@api_bp.after_request
def _release_request_hardware_reservation(response):
    if getattr(g, "scan_hardware_lock_acquired", False):
        g.scan_hardware_lock_acquired = False
        camera_lock = getattr(g, "scan_hardware_operation_lock", None)
        if camera_lock is not None and camera_lock.locked():
            threading.Thread(
                target=_release_after_camera_operation,
                args=(camera_lock,),
                name="camera-hardware-quarantine",
                daemon=True,
            ).start()
        else:
            _scan_hardware_lock.release()
    return response


def _release_after_camera_operation(camera_lock: threading.Lock) -> None:
    camera_lock.acquire()
    camera_lock.release()
    _scan_hardware_lock.release()


@api_bp.route("/", methods=["GET"])
def index():
    return send_from_directory(str(_WEB_DIR), "index.html")


@api_bp.route("/app.js", methods=["GET"])
def web_app_script():
    return send_from_directory(str(_WEB_DIR), "app.js")


@api_bp.route("/style.css", methods=["GET"])
def web_styles():
    return send_from_directory(str(_WEB_DIR), "style.css")


@api_bp.route("/viewer3d.js", methods=["GET"])
def web_3d_viewer_script():
    return send_from_directory(str(_WEB_DIR), "viewer3d.js")


def _initialize_driver(driver: Any, name: str) -> None:
    """Attempt to connect a driver without aborting startup."""
    if driver is None:
        logger.warning("%s not available", name)
        return

    try:
        if not driver.connect():
            last_error = getattr(driver, "last_error", None)
            if last_error is not None:
                logger.warning("%s connection failed", name, exc_info=last_error)
            else:
                logger.warning("%s connection failed", name)
    except Exception as exc:  # pragma: no cover - hardware dependent
        logger.warning("%s connection error", name, exc_info=exc)
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

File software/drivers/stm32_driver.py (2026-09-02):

"""STM32 driver for HoralScanner motor and fan control.

Supports simulation mode (no hardware required) for the test suite.
"""
from __future__ import annotations

import logging
import re
import threading
import time
from typing import Callable

logger = logging.getLogger(__name__)

_HARD_X_MAX_MM = 195.0

_FAN_CHANNELS: dict[str, str] = {
    "creality": "PA0",
    "temperature": "PA8",
}

# Used when no hardware_config is provided at all.
_DEFAULT_MOTOR_CONFIG: dict[str, dict] = {
    "x": {"rotation_distance": 1, "microsteps": 16, "steps_per_rotation": 200,
          "position_min": 0, "position_max": 195, "default_speed_mm_s": 6.25},
    "y": {"rotation_distance": 1, "microsteps": 16, "steps_per_rotation": 200,
          "position_min": 0, "position_max": 628.32, "default_speed_mm_s": 6.25},
    "z": {"rotation_distance": 1, "microsteps": 16, "steps_per_rotation": 200,
          "position_min": 0, "position_max": 270, "default_speed_mm_s": 6.25},
}

# Per-key fallbacks applied when hardware_config IS provided.
_MOTOR_FORMULA_DEFAULTS: dict = {
    "microsteps": 16,
    "steps_per_rotation": 200,
    "default_speed_mm_s": 50,
    "position_min": 0,
    "position_max": float("inf"),
}


def _mm_to_steps(axis_cfg: dict, mm: float) -> int:
    spm = (axis_cfg["steps_per_rotation"] * axis_cfg["microsteps"]) / axis_cfg["rotation_distance"]
    return int(round(abs(mm) * spm))


def _mm_s_to_steps_s(axis_cfg: dict, mm_s: float) -> int:
    spm = (axis_cfg["steps_per_rotation"] * axis_cfg["microsteps"]) / axis_cfg["rotation_distance"]
    return int(round(mm_s * spm))


class STM32Driver:
    """Driver for the STM32 co-processor managing motors and fans."""

    def __init__(
        self,
        simulation: bool = True,
        hardware_config: dict | None = None,
        serial_factory: Callable | None = None,
    ) -> None:
        self._simulation = simulation
        self._hardware_config = hardware_config or {}
        self._serial_factory = serial_factory
        self._port = None  # serial port object once connected
        self._io_lock = threading.Lock()
        self._motion_lock = threading.Lock()
        self._stop_generation = 0
        self._connected = False
        self._last_error: Exception | None = None
        temperature_cfg = self._hardware_config.get("temperature", {})
        fan_cfg = temperature_cfg.get("board_fan_control", {})
        self._board_fan_auto = bool(fan_cfg.get("auto_control", True))
        self._board_fan_on_temp = float(fan_cfg.get("on_temp_c", fan_cfg.get("target_temp", 37) + 2))
        self._board_fan_off_temp = float(fan_cfg.get("off_temp_c", fan_cfg.get("target_temp", 37) - 2))
        if self._board_fan_on_temp <= self._board_fan_off_temp:
            raise ValueError("board fan on temperature must be greater than off temperature")
        self._board_fan_error: str | None = None
        self._board_fan_on = False

        # Fan status
        self._fan_status: dict[str, float] = {name: 0.0 for name in _FAN_CHANNELS}

        # Motor config: when hardware_config is None use _DEFAULT_MOTOR_CONFIG; otherwise
        # use formula defaults merged with any per-axis overrides from hardware_config.
        motors_override = (hardware_config or {}).get("motors", {})
        self._motor_cfg: dict[str, dict] = {}
        for axis in ("x", "y", "z"):
            if hardware_config is None:
                self._motor_cfg[axis] = dict(_DEFAULT_MOTOR_CONFIG[axis])
            else:
                base = dict(_MOTOR_FORMULA_DEFAULTS)
                base.update(motors_override.get(axis, {}))
                self._motor_cfg[axis] = base

        self._motor_status: dict = {
            "positions": {a: 0.0 for a in ("x", "y", "z")},
            "moving": {a: False for a in ("x", "y", "z")},
            "homed": {a: False for a in ("x", "y", "z")},
            "temperature_c": 0.0,
        }

    # ------------------------------------------------------------------
    # Connection
    # ------------------------------------------------------------------

    @property
    def connected(self) -> bool:
        return self._simulation or self._port is not None

    @property
    def last_error(self) -> Exception | None:
        """Last exception raised while attempting to connect, if any."""
        return self._last_error

    def connect(self) -> bool:
        self._last_error = None
        if self._simulation:
            self._connected = True
            return True
        serial_cfg = self._hardware_config.get("serial", {})
        port = serial_cfg.get("mcu_port", "/dev/horalscanner_mcu")
        baud = serial_cfg.get("baud", 115200)
        timeout = serial_cfg.get("timeout_s", 1.0)
        factory = self._serial_factory
        if factory is None:
            try:
                import serial as _serial
                factory = _serial.Serial
            except ImportError as exc:  # pragma: no cover
                self._last_error = exc
                self._connected = False
                return False
        try:
            self._port = factory(port, baud, timeout=timeout, write_timeout=timeout)
            self._port.reset_input_buffer()
            self._connected = True
            return True
        except Exception as exc:
            self._last_error = exc
            self._port = None
            self._connected = False
            return False

    # ------------------------------------------------------------------
    # Internal helpers (can be monkey-patched in tests)
    # ------------------------------------------------------------------

    def _send_command(self, cmd: str) -> bool:
        if self._simulation:
            return True
        if self._port is None:
            return False
        with self._io_lock:
            self._port.write((cmd + "\n").encode())
            response = self._port.readline().decode("ascii", errors="replace").strip()
        return response.startswith("OK")

    def _send_and_read(self, cmd: str) -> str:
        """Send command and return raw response line."""
        if self._port is None:
            return ""
        with self._io_lock:
            self._port.write((cmd + "\n").encode())
            return self._port.readline().decode("ascii", errors="replace").strip()

    def _send_motion_command(self, cmd: str, generation: int) -> bool:
        """Order motion against STOP without making STOP wait on a whole move."""
        if self._simulation:
            if generation != self._stop_generation:
                return False
            return self._send_command(cmd)
        if self._port is None:
            return False
        with self._io_lock:
            if generation != self._stop_generation:
                return False
            self._port.write((cmd + "\n").encode())
            response = self._port.readline().decode("ascii", errors="replace").strip()
            return response.startswith("OK")
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

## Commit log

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2026-08-22 fix: finalize custom USB firmware scaffold and scan control flow
    [pi_hardware.py, scanner_controller.py, test_scanner_controller.py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]
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2026-08-22 fix: align usb frames and absolute scan offsets
    [motor_control.py, test_scanner_controller.py, test_usb_driver.py]
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2026-08-22 Fix review issues: pin conflict, schematic tag, FAN_OFF macro, Moonraker update branch
    [creality_v422_usb.cfg, temperature_fan.cfg, thermostat_circuit.sch]
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2026-08-22 Fix log file path to use home directory
    [config.py]
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2026-08-23 Fix: avoid exposing internal exception details in API error response
    [creality_api.py]
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2026-08-23 fix: Address code review feedback
    - viewer3d.js: dispose mesh material to prevent WebGL memory leak
    - slicer.js: wrap _doSlice in try/catch for network errors
    - horalscanner_api.py: restrict /api/update to localhost only
    - settings.js: do not persist Moonraker API key to localStorage
    - queue.js: remove localStorage API key lookup (use backend config)
    [horalscanner_api.py]
2026-08-23 fix: Sanitize exception messages in API responses (CodeQL py/stack-trace-exposure)
    Log full exception details server-side but return generic error strings
    to clients to avoid exposing internal paths or stack traces.
    [horalscanner_api.py, scanner_engine.py, slicer_bridge.py]
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2026-08-23 fix: address code review issues (STM32 connected flag, LED animation threading, RGB bounds validation)
    [gpio_driver.py, led_control.py, stm32_driver.py]
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2026-08-23 fix: address STM32 driver review feedback
    [horalscanner_api.py, stm32_driver.py]
2026-08-23 fix: use POST for model reconstruction
    [horalscanner_api.py]
2026-08-23 fix: sanitize hardware API error responses
    [horalscanner_api.py, led_control.py, motor_control.py]
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2026-08-23 fix: validate API numeric payload parsing
    [horalscanner_api.py, test_horalscanner_api.py]
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2026-08-23 fix: harden API error and runtime handling
    [horalscanner_api.py]
2026-08-23 fix: Remove invalid 'initial' parameter from OutputDevice and use PWMLED for PWM pins
    [gpio_driver.py]
2026-08-23 fix: Add repo root to sys.path for proper driver imports
    [horalscanner_api.py]
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2026-08-23 fix: harden fan parsing and temperature error handling
    [horalscanner_api.py, test_horalscanner_api.py]
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2026-08-24 fix(serial): stable USB aliases for Creality/TF-Luna; add /health endpoint; restore GPIODriver compatibility
    [gpio_driver.py, horalscanner_api.py, lidar_driver.py]
2026-08-24 Fix 500 errors on laser/motor/fan status endpoints by implementing missing driver methods (#27)
    * Initial plan
    * Fix runtime API incompatibilities: add missing driver methods for status endpoints
    ---------
    [gpio_driver.py, stm32_driver.py, test_gpio_driver.py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]
2026-08-25 Fix gpio_driver.py: rename class STM32Driver → GPIODriver (#28)
    * Fix gpio_driver.py: rename class STM32Driver to GPIODriver
    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
    [gpio_driver.py]
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2026-08-26 Fix Creality endstop polarity
    Treat all normally closed endstops as active-high so homing starts while released and stops when the switch opens at the mechanical reference.
    [main.cpp]
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2026-08-26 Add side fixings to camera mount
    Add independent M3 pilot holes on both sides so the rear-cavity base can be secured through newly drilled holes in the red scanner housing.
    [fit_test_rear_cavity_52.8x15.5.stl, pi_camera_tilt_base.stl]
2026-08-26 Resize Pi Camera mount base
    Apply the printed fit-test corrections and constrain both the test coupon and complete mount to 38.20 by 30.45 mm.
    [fit_test_rear_cavity_38.2x30.45.stl, fit_test_rear_cavity_52.8x15.5.stl, pi_camera_tilt_base.stl]
2026-08-26 Redesign Pi Camera pivot ears
    Replace the tall cradle walls with a centered M3 clevis using 8.70 mm ears, a 5.33 mm support gap, 5.99 mm height, and 24 mm side walls while retaining the validated flat base.
    [fit_test_rear_cavity_38.2x30.45.stl, pi_camera_tilt_base.stl]
2026-08-26 Correct Pi Camera mount geometry
    Place rounded 8.50 mm pivot ears on the 30.45 mm front edge with an 8.70 mm projection and 5.33 mm center gap, while moving the 24 mm walls to the rear and lowering the 16.90 mm center strip by 5 mm.
    [fit_test_rear_cavity_38.2x30.45.stl, pi_camera_tilt_base.stl]
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2026-08-28 fix(ci): replace fragile HTML scraping with Raspberry Pi Imager JSON API for OS image URL resolution (#42)
    * fix: replace HTML scraping with Raspberry Pi Imager JSON API for image URL resolution
    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
2026-08-29 Update Pi camera tilt mount CAD for 30.45×38.20 plate orientation, centered shelf CSI cutout, and M5×45 lower adjustment clearance (#44)
    * Update Pi camera tilt mount geometry for 30.45x38.20 plate and M5 adjustment hole
    * Refine CSI slot placement and clean CAD parameter naming
    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
    [fit_test_rear_cavity_30.45x38.2.stl, fit_test_rear_cavity_38.2x30.45.stl, pi_camera_tilt_base.stl]
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2026-08-29 Correct Pi camera tilt adjustment hole axis to rear→front on vertical plate (#46)
    * Fix Pi camera adjustment hole orientation rear-to-front
    * Clarify rear-face reference for adjustment hole
    * Document and stabilize rear-to-front hole definition
    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
    [pi_camera_tilt_base.stl]
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2026-08-29 Add M5 helical thread to ball screw and 4-petal snap-fit socket to camera support plate (#48)
    * Add M5 helical thread to ball screw, petal snap-fit to support plate, update README and regenerate STLs
    * Fix TopExp_Explorer.Value() usage and correct cone chamfer placement via BRepPrimAPI_MakeCone
    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
    [ball_screw_M5x40_ball6.5.stl, camera_support_plate_28.05x7x1.stl]
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2026-08-30 Resolve PR #55 merge conflicts by consolidating camera calibration flow, per-camera pose memory, and TF‑Luna validation (#57)
    * Resolve calibration merge leftovers and unify camera pose workflow
    * Finalize calibration workflow conflict resolution in API/UI/tests
    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
    [horalscanner_api.py, test_calibration_pose.py, test_horalscanner_api.py]
2026-08-30 Fix unresolved merge conflict in camera calibration UI
    [fit_test_27.6x7.3.stl]
2026-08-30 feat: automatic camera calibration positioning, scan-pose memory, and TF-Luna integration (#56)
    * feat: automatic camera calibration pose, scan-pose memory, and TF-Luna integration
    * fix: remove exception details from user-facing error messages (CodeQL py/stack-trace-exposure)
    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
    [camera_calibration.py, horalscanner_api.py, test_camera_calibration.py]
2026-08-30 feat: automatic Pi camera calibration pose workflow (#52)
    * feat: add Pi camera calibration pose automation
    - Add CALIBRATION_POSES constant in horalscanner_api.py defining
    the Pi camera calibration pose (X=0 centre, Y=0 orientation, Z=None)
    - Add POST /api/calibration/pose/<camera> route: homes all axes then
    moves to the predefined calibration position
    - Add "Mise en pose automatique" section in calibration tab (index.html)
    with a "Aller a la pose" button for Pi Camera V3
    - Add gotoCalibrationPose() JS handler in app.js with user feedback
    - Add 4 new tests covering success, unknown camera (400), no STM32 (503),
    and homing failure (502)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
2026-08-30 fix(ci): restore pytest collection by adding missing compatibility shims (#24)
    * fix(ci): add compatibility shims for GPIOLaserControl, USBDriver, GPIODriver, STM32Driver
    * Resolve merge conflicts with main for PR #24
    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
    [scanner_app.py]
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2026-08-30 Fix CI: add compatibility shims to unblock pytest collection (#22)
    * Fix CI: add GPIOLaserControl, USBDriver shims and missing software drivers
    * Plan: implement full STM32Driver and GPIODriver, update CI workflow
    * Implement full STM32Driver and GPIODriver; update CI to run pytest from software/
    ---------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
    [gpio_driver.py, gpio_laser_control.py, stm32_driver.py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]
2026-09-01 Fix API startup: use api_bp routes and avoid circular config_manager import
    [horalscanner_api.py]
2026-09-01 fix(api): use api_bp route decorator and avoid circular import for config_manager
    [horalscanner_api.py]
2026-09-01 Add scanner API health endpoint and startup import regression coverage (#60)
    * fix(api): add health endpoint coverage and startup regression tests
    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
    [horalscanner_api.py, test_calibration_pose.py, test_camera_calibration.py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]
2026-09-01 [WIP] Audit and fix web-to-hardware actions on Raspberry Pi 4 (#61)
    * Apply remaining changes
    * Add Pi 4 simulation fallback and runtime status feedback
    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
    [config_manager.py, horalscanner_api.py, scanner_engine.py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]
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2026-09-01 fix(camera): USB fallback indices and read validation
    [camera_driver.py]
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2026-09-01 Merge main into camera-USB-fix branch, resolve camera_driver.py conflict (#63)
    * Fix USB camera fallback logic, add docs and tests
    * Address code review: preserve log order, fix JSON doc notation
    * Resolve merge conflict: accept PR version with improved fallback logging and class-level FALLBACK_DEVICE_IDS constant
    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
    [camera_driver.py, test_camera_driver.py, test_horalscanner_api.py]
2026-09-01 [WIP] Fix GPIO configuration for lasers and RGB LEDs (#64)
    * Fix GPIO and STM32 hardware status
    * Handle partial GPIO status attributes
    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
    [gpio_driver.py, horalscanner_api.py, stm32_driver.py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]
2026-09-01 Surface actual connect() exceptions instead of generic "connection failed" logs (#65)
    * Log actual connect() exceptions in GPIODriver/STM32Driver
    * Avoid duplicating exception message when logging via exc_info
    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
    [gpio_driver.py, horalscanner_api.py, stm32_driver.py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]
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2026-09-01 Fix USB camera fallback detection; add fan/laser/RGB API contract docs and tests (#62)
    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
2026-09-01 Fix M5 ball-screw retention: recess ball, repair petal-ring anchoring, add shaft passage (#74)
    * Fix M5 ball-screw retention: recess ball, fix plate petal ring + M5 through-passage
    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
    [ball_screw_M5x40_ball6.5.stl, camera_support_plate_28.05x7x1.stl, pi_camera_tilt_base.stl]
2026-09-01 Add missing PR #23 compatibility test coverage for GPIO/USB wrappers (#73)
    * Add compatibility tests for GPIOLaserControl/USBDriver/ScannerApp (PR #23)
    * Address code review: move struct import to top of test file
    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
    [test_usb_driver_compat.py]
2026-09-01 Expose Raspberry Pi and Creality 4.2.2 temperatures (#75)
    * Add Pi and MCU temperature reporting
    * Fix Pi temperature test placement
    * Expose both hardware temperatures
    * Harden temperature driver status
    * Release GPIO devices on shutdown
    * Remove merge conflict markers from temperature tests
    * Remove merge conflict marker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
    [gpio_driver.py, horalscanner_api.py, stm32_driver.py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]
2026-09-01 swap PLATE_WIDTH/PLATE_HEIGHT on pi_camera_tilt_mount base plate (#43)
    * swap PLATE_WIDTH and PLATE_HEIGHT, update README and regenerate STL
    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
    [pi_camera_tilt_base.stl]
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2026-09-02 fix: numpy version constraints for ARM64 Raspberry Pi compatibility
    numpy 2.5.2 is not available on piwheels (ARM64). Use numpy 2.0-2.1 on ARM64,
    allow 2.5+ on x86/amd64. Prevents pip install failure on RPi4.
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2026-09-02 Add Creality 4.2.2 temperature self-check and automatic fan control (#85)
    * Implement Creality temperature monitoring
    * Test automatic Creality fan control
    * Fix temperature/board route missing board_c key
    * Surface camera/GPIO/STM32 activation errors; add direct hardware diagnostic script; fix DSI->CSI terminology
    * Fix Pi Camera (CSI) red/blue channel swap from picamera2 BGR quirk
    Co-authored-b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
    [camera_acquisition.py, camera_driver.py, config.py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]
2026-09-02 Fix camera diagnostics timeouts and overlap
    Serialize camera access, bound capture and analysis requests, downsample checkerboard detection, automatically probe USB cameras, and keep dashboard health polling from overlapping diagnostics.
    [camera_driver.py, diagnose_hardware.py, horalscanner_api.py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]
2026-09-02 Contain initial motor status failures
    [scanner_engine.py, test_scanner_engine.py]
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2026-09-02 Correct calibration board to 10x6 corners
    [camera_driver.py, scanner_engine.py, test_camera_driver.py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]
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2026-09-02 Fix carriage calibration references and persistence
    Use each moving sensor's absolute calibration reference during scans, validate reference bounds, move measured calibration into durable runtime state, and add an idempotent Raspberry Pi OS repair workflow.
    [config_manager.py, horalscanner_api.py, scanner_engine.py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]
2026-09-02 Make Pi repair camera environment fail-safe
    Always expose Raspberry Pi OS packages in fresh and upgraded virtual environments, validate libcamera and all runtime imports before touching systemd, and prevent broken repair attempts from restarting the service.
    [test_setup_pi.py]
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2026-09-02 Handle broken repair venv and late cancellation
    Recreate only a validated venv path when its interpreter cannot execute, and prevent near-deadline calibration cancellation from being converted into a timeout or reaching diversity and persistence.
    [test_geometric_calibration.py, test_setup_pi.py]
2026-09-02 Fix calibration capture around LiDAR glare
    [checkerboard_detector.py, config.py, lidar_driver.py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]
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2026-09-03 Fix mechanism-aware geometric calibration
    Replace center-dependent diversity checks with corner-shape metrics, recover signed axis geometry from PnP observations, and persist the observed turntable command model for scanning.
    [horalscanner_api.py, scanner_engine.py, test_geometric_calibration.py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]
2026-09-03 Fix runtime turntable pivot at scan X
    Derive per-frame and scan-origin turntable centers from the persisted reference X and signed command scale before undoing Y rotation.
    [scanner_engine.py, test_scanner_engine.py]
2026-09-03 Fix opposed camera axis fitting
    [test_geometric_calibration.py]
2026-09-03 Fix planar PnP convention selection
    [test_geometric_calibration.py, test_scanner_engine.py]
2026-09-03 Harden laser plane calibration
    Use checkerboard-scoped coherent laser extraction, Pi-authoritative plane evidence, and the measured USB carriage vector for TF-Luna correction.
    [scanner_engine.py, test_geometric_calibration.py, test_scanner_engine.py]
2026-09-03 Fix calibration transaction review blockers
    [horalscanner_api.py, scanner_engine.py, test_camera_calibration.py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]
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2026-09-03 Stabilize USB carriage vector fitting
    [test_geometric_calibration.py]
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2026-09-03 Fix rotary Y index homing
    Require a stable index release before accepting the next stable trigger when Y homing begins on PA6, while preserving existing X/Z and move behavior.
    [main.cpp]
2026-09-03 Stabilize USB carriage Z fit
    Balance the calibration trajectory with direct same-XY Z contrasts and use a bounded multivariate estimator while retaining every production gate.
    [test_geometric_calibration.py]
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2026-09-04 Select qualified checker-gap ridge peaks
    Choose co-located sharp chromatic peaks before evaluating centered and competing ridge runs, preventing stronger checker artifacts from masking the real centerline.
    [test_geometric_calibration.py]
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2026-09-05 Address code review feedback on calibrated_sides validation and error messages
    [test_geometric_calibration.py]
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2026-09-07 fix(cad): regenerate pi camera tilt base STL assets from generator (#123)
    [fit_test_rear_cavity_30.45x38.2.stl, pi_camera_tilt_base.stl]
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2026-09-07 [WIP] Fix code based on review comment for PR #124 (#125)
    * Remove duplicate camera tilt STL profile
    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
2026-09-09 Fix/stl pi tilt base 30.45x38.2 (#138)
    * fix(cad): regenerate pi camera tilt base STL assets from generator
    * Rectifying STL file for camera tilt mount (#134)
    * Regenerate camera tilt mount STL from CAD source
    * Fix CSI cut-out position for L-shape camera mount
    * Apply remaining changes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
    [adjustment_rod_M5x50_ball6.5_square_m3.stl, pi_camera_tilt_base.stl, wheel_crank_50mm_square_m3.stl]
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2026-10-02 Lock manual exposure/gain on USB camera open to fix checkerboard detection failures
    Opening a fresh cv2.VideoCapture resets the UVC driver's auto-exposure/gain
    to power-on defaults, silently discarding any externally-applied v4l2-ctl
    settings. This made the USB camera badly overexpose (~29% of pixels
    clipped to white) during geometric calibration regardless of the exposure/
    gain the operator configured beforehand, so no checkerboard corners could
    ever be detected on that camera.
    LogitechCamera now accepts an optional photometry dict of manual V4L2
    controls, re-applied via v4l2-ctl right after the device is confirmed open
    so the settings actually stick, with a few frames discarded afterwards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
    [camera_driver.py, horalscanner_api.py, test_camera_driver.py]
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2026-10-02 fix(calibration_pose): correct goto_calibration_pose target to X=175/Z=120 and fix stale position read
    The /api/camera/<camera>/goto_calibration_pose route uses calibration_pose.py (not camera_calibration.py). Its LOGITECH_DEFAULT_POSE still held the old unvalidated x=100/z=150 pose, and move_to_pose() read motor status once before the per-axis loop, causing stale deltas when axes mechanically couple. Fixed both: updated pose constant to the empirically validated X=175/Z=120, and re-read motor status fresh before each axis move. Verified end-to-end: goto_calibration_pose now lands exactly at x=175/z=120 and find_checkerboard_bounded succeeds (found=True).
    [calibration_pose.py, camera_calibration.py]
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2026-10-02 fix(lidar): persist TF-Luna offset calibration across restarts
    The known-distance offset computed by /api/lidar/calibrate was only
    kept in memory and reset to 0 on every service restart, even though
    config/horalscanner.json already had an unused lidar_offset_mm field.
    - LidarDriver.__init__ now accepts offset_mm and applies it on load
    - horalscanner_api.py now seeds LidarDriver from scanner_config['lidar_offset_mm']
    - /api/lidar/calibrate now persists the computed offset via config_manager.save()
    Verified: real TF-Luna read 270-280mm at the calibration pose against a
    physically measured 295mm. Recalibrated to offset_mm=15.0, confirmed
    reading now matches 295mm, and confirmed the offset sur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
    [horalscanner_api.py, lidar_driver.py]
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2026-10-04 fix(calibration): accept auto-calibrated TF-Luna source in validators
    validate_calibration_payload and scanner_engine startup validation only recognized source == operator_measured_origin_direction, rejecting the new auto_calibrated_least_squares value with TF-Luna transform source is not recorded even though the fit itself succeeded.
    [scanner_engine.py]
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2026-10-04 Fix remaining hardcoded minimum_board_orientations floor in scan preflight
    The provenance_valid check in scan preflight still required
    minimum_board_orientations >= 3, missed in the previous commit's fix of
    _laser_pose_consensus_valid. Lowered to >= 2 to match the relaxed
    calibration config.
    [scanner_engine.py]
2026-10-04 Fix TypeError crash in analyze_laser_line on non-standard HoughLinesP shape
    cv2.HoughLinesP does not always return a consistent (N, 1, 4) array shape;
    in some cases it returns (N, 4), making line[0] a scalar instead of a
    4-tuple and raising 'cannot unpack non-iterable numpy.int32 object'.
    This crashed on every laser-capture frame during a real scan of a 3D
    object (irregular laser-line geometry triggers this HoughLinesP shape
    more often than the flat calibration checkerboard), and the exception
    was silently swallowed by _laser_line_detected's except-return-False
    handler, producing 'no calibrated laser points' for every camera/side.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
    [camera_driver.py]
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2026-10-06 Fix undefined ADJUSTMENT_BOSS constants in camera carrier (align to M5 thread hole)
    [camera_carrier_v3_25x24_tab4.8.stl]
2026-10-07 Fix lens hole not fully cut through front cover (wrong Y reference)
    The lens_hole cylinder started from cover_back_y instead of cover_front_y,
    leaving a ~0.6mm uncut slab blocking the lens opening in the printed part.
    [camera_front_cover_v3_clip.stl]
2026-10-07 Fix M5 thread hole not cut through full plate thickness on base
    m5_thread_hole started at y=0 (plate center) instead of the front face,
    leaving the front half of the plate uncut. The adjustment rod could not
    pass through to reach the carrier's ball socket.
    [pi_camera_tilt_base.stl]
2026-10-07 Fix adjustment rod ball tangent-only contact
    The ball sphere only touched the rod cylinder at a single tangent point
    (zero overlap), so boolean fuse produced two separate solids instead of
    one watertight body. Sinks the ball 1mm into the rod (BALL_OVERLAP) to
    create a real overlapping neck, verified continuous/solid by ray-cast.
    [adjustment_rod_M5x50_ball6.5_square_m3.stl]
2026-10-07 Model a real external thread on the adjustment rod
    The rod was a smooth Ø5.00mm cylinder meant to screw into a Ø4.20mm
    pilot hole: it physically could not fit, let alone thread in, since
    no helical thread geometry existed anywhere in the CAD.
    Adds make_external_thread(): sweeps a triangular V-profile along a
    helix (Geom_CylindricalSurface + 2D line mapped to its UV space,
    BRepOffsetAPI_MakePipeShell) to cut a real, printable coarse thread
    (Ø6.00mm major / Ø4.50mm minor, 2.00mm pitch, 16mm engagement length)
    on the rod. The base's tapped hole is resized to Ø5.00mm (major - 1mm)
    so the crests compress into the pilot hole as the rod is turned in,
    self-tapping its own mating groove, withou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
    [adjustment_rod_M5x50_ball6.5_square_m3.stl, pi_camera_tilt_base.stl, wheel_crank_50mm_square_m3.stl]
2026-10-07 Fix camera tilt mechanism: flat ball pad, carrier clearances, shelf relief
    - Replace the spherical ball-socket dimple with a flat-bottomed pad
    (BALL_SOCKET_PAD_RADIUS/BALL_SOCKET_DEPTH): a sphere against a plane
    keeps contact at any angle, unlike the old matching-radius socket whose
    usable range was only ~+/-2.4deg before losing contact.
    - Fix the carrier hinge tab reusing the base ears' deep-anchor formula,
    which made the free-pivoting tab physically penetrate the main plate's
    solid body even at rest (0deg).
    - Add a wall relief notch (CARRIER_WALL_CLEARANCE) where the 25mm-wide PCB
    carrier was wider than the shelf's 24.05mm clear inner gap.
    - Increase CARRIER_STANDOFF_GAP from 1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
    [camera_carrier_v3_25x24_tab4.8.stl, camera_front_cover_v3_clip.stl, pi_camera_tilt_base.stl]
2026-10-07 Add CSI ribbon passage in camera carrier (L-shaped opening)
    The FPC connector on the official Pi Camera Module 3 PCB sits on the
    back face, centered in X, 2.10mm from the PCB bottom edge (per the
    official mechanical drawing). With no clearance cut into the carrier's
    board plate behind it, the ribbon had nowhere to route from the
    connector down to the shelf's existing CABLE_PASSAGE -- it would be
    pinched solid.
    Adds an L-shaped opening in the carrier:
    - a full through-slot (visible, real opening) for the lower leg, from
    the carrier's bottom edge up to just below the ball-socket pocket
    - a shallow 0.6mm groove for the short upper leg, cut only into the
    front face up past the connector hei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
    [camera_carrier_v3_25x24_tab4.8.stl]
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2026-10-07 Fix CSI cable passage to cut fully through shelf thickness
    The passage started at z=MATERIAL_THICKNESS/2 instead of z=0, leaving a
    solid 1.6mm floor under the ribbon path. This made it a shallow
    top-side groove rather than an actual through-slot, so the cable had
    no real opening to pass through. Starting the cut at the shelf's
    bottom face (z=0) guarantees a clean cut through the full shelf
    thickness, flush with the carrier's own through-slot above it.
    [pi_camera_tilt_base.stl]
